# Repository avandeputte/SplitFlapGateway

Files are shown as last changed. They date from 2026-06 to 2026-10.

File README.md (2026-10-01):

# Split-Flap Gateway

> ### 🌐 [splitflap.iothing.net](https://splitflap.iothing.net) · 📖 [Documentation](https://splitflap.iothing.net/docs/)
> Quick start · choosing a configuration · provisioning & calibration · the SplitFlap,
> Matrix and LCD gateways · the companion and its apps · APIs and wire protocols — the
> whole ecosystem, documented in one place.

**Firmware version: 3.8.0**

> [!NOTE]
> **New to this project?** Read the [blog post](BLOG.md) for the full story — why it exists, how it works, and how it fits into the split-flap display ecosystem. Calibrating a module? See the **[Module Calibration Guide](CALIBRATION_GUIDE.md)**.

> [!TIP]
> **New in 3.8** (everything since 3.4 — see [RELEASE_NOTES.md](RELEASE_NOTES.md) for the full list)
> - **`GET /api/capabilities`** — one call that tells a client exactly what characters the wall
>   can show (`union`, the wall-wide `common` set, and each distinct reel with the module ids that
>   carry it). The Matrix Portal gateway answers the same URL identically, so a client never has
>   to know which kind of wall it is driving. See [New in 3.7](#new-in-37).
> - **`POST /api/display/cells`** — set a whole row in one call (`{ch|color|blank|skip}` per cell,
>   named colours, cascade pacing), the same contract the Matrix gateway answers, so the companion
>   drives both walls through one endpoint. See [New in 3.8](#new-in-38).
> - **Quiet Time now blanks the wall**, and **every gateway has its own MQTT identity** (two on one
>   broker used to knock each other offline).
> - **Safer web OTA and a security fix** — the watchdog no longer reboots the board mid-flash, and
>   a remotely-reachable buffer overflow in the by-serial flap-config command is closed.

> [!TIP]
> **New in 3.5**
> - **The dashboard speaks your language** — 13 languages plus English, chosen
>   automatically from your **browser** (the same way the light/dark theme is), with an
>   override in Settings and a `?lang=` URL parameter so the companion can request one.
>   All of them ship in the one firmware image. See [Language](#language).
> - **Re-skin fixes** — the Home Assistant theme left several controls behind, and in the
>   **light** theme some were *invisible*: every secondary button (Refresh, Identify All,
>   Home All, Re-read EEPROM) rendered white-on-near-white, and the destructive-action
>   buttons and bus-monitor text were unreadable. All fixed, and every element now clears
>   WCAG AA in both themes. **If you are on v3.4, this is the reason to update.**

> [!TIP]
> **New in 3.4**
> - **A new look** — the dashboard now wears the same **Home Assistant design
>   language** as the companion, so the two feel like one product. It follows your
>   browser/OS **light or dark** preference.
> - **Backup & restore moved into Settings** — the separate **Backup** tab is gone
>   (an old `#backup` link now lands on Settings). Nothing about the backup format
>   or the restore-by-serial behaviour changed.
> - **Tab advertisement** — the gateway and the companion now **tell each other
>   which tabs they have** (`tabs` / `gwTabs` on `POST /api/companion`), so neither
>   hard-codes a list of the other's. Old↔new pairings both still work.
> - **A steadier web server** — batch pacing no longer blocks the HTTP server (see
>   [Batch pacing](#batch-pacing-v34)), the module list streams in chunks (fixing a
>   watchdog reboot on large walls), and a changed MQTT broker now takes effect
>   without a reboot.

> [!TIP]
> **New in 3.2**
> - **Home All** — the Display and Calibration tabs each gained a **Home All**
>   button that homes every module at once (broadcasts `m*h`).

> [!TIP]
> **New in 3.1**
> - **Companion settings stored on the gateway** — the [Companion App](#companion-app)
>   can now park its settings, playlists and triggers in the gateway's flash
>   (`GET`/`PUT /api/companion/settings`), so a companion container becomes
>   stateless: spin one up on any host and it inherits its configuration from the
>   gateway. See [Companion Settings Storage](#companion-settings-storage).
> - **Firmware version in `/api/config`** — the config response now carries a
>   `"version"` field (e.g. `"3.1.0"`), which is how the companion detects a
>   gateway new enough to store its settings.

> [!TIP]
> **New in 3.0**
> - **Batch RS-485 send** — `POST /api/rs485/batch` sends many frames in one
>   request (with optional device-side pacing), so a host can draw a whole
>   animated page in a single HTTP call instead of one request per module.
> - **Quiet-Time schedule** — Quiet Time can now turn on/off automatically on a
>   daily schedule (Settings → *Quiet Time Schedule*: a start/end time and the
>   days it applies). Evaluated once a second against the RTC.
> - **Companion app** — the companion that adds apps, playlists and triggers is
>   **released**: [SplitFlapGatewayCompanion](https://github.com/avandeputte/SplitFlapGatewayCompanion).

---

> [!IMPORTANT]
> **This project is designed to work with the Split-Flap display from [Adam G Makes](https://www.youtube.com/@AdamGMakes).**
> See [this video](https://youtu.be/-C8_AtxEEQc?si=Gym5wikeFH2vUNRm) for additional information.
>
> - **Basic functionality** (sending characters and text to the display) works with Adam's original firmware using hardcoded module IDs — no provisioning required.
> - **Full functionality** (module discovery, dynamic ID assignment, and provisioning) requires the universal firmware: [avandeputte/SplitFlapUniversalFirmware](https://github.com/avandeputte/SplitFlapUniversalFirmware).

---

## New in 3.7

- **`GET /api/capabilities`** — one call that answers *what characters can this wall show?* The
  Matrix Portal gateway answers the same URL with the same shape, so a client never has to know
  which kind of wall it is talking to.

  On a real wall the answer is not one set. Every module owns its reel, and since module firmware
  v31 each can be told a *different* one (`N`), so the response reports both:

  | field | question it answers |
  |---|---|
  | `union` | can this wall show a `Z` **anywhere**? |
  | `common` | can I lay this text across **arbitrary** cells? |

  These genuinely differ. If module 1 carries `A-Z` and module 2 carries `0-9`, the union is
  `A-Z0-9` but the common set is *empty* — the wall cannot show `HI42` wherever it likes, and
  only `common` says so. `sets` then lists each **distinct** reel once with the ids that carry it
  (`"0-44,50"`), so a uniform wall is a few hundred bytes however large it is.

  Two translations are applied, matching exactly what the gateway does when it resolves a frame:
  the seven colour flaps `r o y g b p w` are reported by name under `colors` and kept *out* of the
  character sets, and `q` — which the classic reel borrows for the double-quote flap — is reported
  as `"`. A client that read those as letters would believe a classic reel can show a lowercase
  `w`.

- **The registry now remembers each module's flap set**, read from the v31+ tail of an `A` reply
  and **persisted**. That is not an optimisation: an `A` reply is ~200 bytes, so asking a
  45-module wall costs about **ninety seconds of bus time** at 9600 baud. Paying that on every
  reboot — or flooding the bus with a wall-wide `m*A` at boot — would be absurd. Unknown sets are
  filled by a slow background trickle (one module every 2 s), a set is re-read only when an `N`
  deliberately changes it, and the file magic is bumped to `SFG3`.

  Modules older than v31 cannot report a set. Their reel is *assumed* to be the firmware's
  built-in default and their ids are listed under `charset.assumed`, so the guess is visible
  rather than folded in silently — a gateway that hid it would be lying at exactly the moment
  someone had reflashed a module with a custom reel. Modules whose set is genuinely not known yet
  are listed under `unknown` and excluded from both character sets.

- **`tools/capset_test.cpp`** — the set arithmetic (union, intersection, range compression, the
  `q` and colour translations) compiles the firmware's own `src/capset.h`, so the test exercises
  the shipped code rather than a copy of it. It covers the case that cannot be reproduced without
  physically rebuilding the wall: modules with different reels.

## New in 3.8

- **`POST /api/display/cells`** — set a run of modules in one call, the **same JSON contract the
  Matrix Portal gateway answers**, so a client (the companion) can drive both walls through one
  display endpoint instead of this wall's batch/char path and the Matrix's cells path. It is the
  "show this" companion to `GET /api/capabilities` ("what can you show").

  ```json
  { "start": 0, "step_ms": 15,
    "cells": [ {"ch":"H"}, {"ch":"I"}, {"color":"red"}, {"blank":true}, {"skip":true} ] }
  ```

  Each cell is exactly one of `ch` (a character), `color` (a named flag: red orange yellow green
  blue purple white), `blank` (home the module), or `skip` (leave it alone). `step_ms` (0–100)
  paces the cascade, scheduled on the RS-485 task rather than blocking the web server.

  It is **lenient**, and that is the one real difference from the Matrix's strict form: this wall's
  modules each carry their own reel and can differ, so a cell that cannot be shown (a glyph absent
  from the reel, an unknown colour name) is **skipped** rather than failing the whole row — the
  response reports `sent` vs `skipped`. Only structural errors (bad JSON, missing `cells`) return
  400. A client that needs certainty consults `/api/capabilities` first.

  Sent **by character** (`m<id>-<char>`), not by index like the Matrix: index *N* names a different
  glyph on a module with a different reel, whereas the byte lets each module map it against its own.

## New in 3.12

- **Restore on boot** — upload a calibration backup to the gateway and have it **replayed to
  every module on every boot**. Each module's calibration (home offset, steps per revolution,
  flap map, and a v31+ flap set) and its **ID** are written by serial number, read back and
  verified, and the whole wall is homed at the end. While it runs the gateway **refuses every
  other module command** — REST answers `503 {"error":"restore in progress"}`, MQTT commands
  are dropped — and the dashboard shows a red border and banner with the progress. It always
  finishes on its own (a module that never answers is counted, not waited for), and it can be
  started or cancelled by hand. Settings tab → **Restore on Boot**; see
  [Restore on Boot](#restore-on-boot).

## Table of Contents

- [Hardware](#hardware)
- [Features](#features)
- [Installation](#installation)
- [Serial Debug Output](#serial-debug-output)
- [First Boot](#first-boot)
- [Web UI](#web-ui)
  - [Language](#language)
- [Companion App](#companion-app)
  - [Companion Settings Storage](#companion-settings-storage)
- [Module List Persistence](#module-list-persistence)
- [Restore on Boot](#restore-on-boot)
- [Split-Flap Protocol](#split-flap-protocol)
- [REST API](#rest-api)
  - [RS-485 Bus](#rs-485-bus)
  - [Module Control](#module-control)
  - [Advanced Module Commands](#advanced-module-commands)
  - [Provisioning](#provisioning)
  - [Status and Configuration](#status-and-configuration)
  - [OTA Firmware Update](#ota-firmware-update)
- [OpenAPI Specification](#openapi-specification)
- [MQTT](#mqtt)
- [Time Configuration](#time-configuration)
- [OTA Firmware Updates](#ota-firmware-updates)
- [Default Settings](#default-settings)
- [License](#license)

---

## Hardware

**Target board:** [Waveshare ESP32-S3-RS485-CAN](https://www.waveshare.com/wiki/ESP32-S3-RS485-CAN) — [Buy on Amazon](https://www.amazon.com/dp/B0FNCWZ3D1?ref=ppx_yo2ov_dt_b_fed_asin_title)

| Function | Pin |
|---|---|
| RS-485 TX | GPIO 17 |
| RS-485 RX | GPIO 18 |
| RS-485 DE/RE | GPIO 21 |
| I²C SDA (RTC) | GPIO 39 |
| I²C SCL (RTC) | GPIO 38 |
| RTC chip | PCF85063 @ 0x51 |
| Debug serial | Native USB CDC (`/dev/cu.usbmodem*` on macOS, `COMx` on Windows, `/dev/ttyACM0` on Linux) |

The RS-485 bus runs at **9600 baud, 8N1**.

> **Mount it on the rail.** [`SplitFlapGatewayCase.3mf`](SplitFlapGatewayCase.3mf) is a printed
> case that replaces the Waveshare enclosure, clips the gateway onto the modules' DIN rail, and
> takes 12 V and the RS-485 bus from the conductor rail through four pogo pins — no wiring to
> the wall at all. The build, and the soldering it needs, is on the wiki:
> **[Gateway Case](https://splitflap.iothing.net/docs/Gateway-Case/)**.

---

## Features

- **Web UI** — single-page dashboard accessible from any browser, in the same **Home Assistant design language** as the companion (light or dark, following your browser/OS)
- **[Companion app](#companion-app)** — an optional content engine (apps, playlists, schedules, triggers) that runs on a Raspberry Pi or any Linux box and drives the display over REST. It registers itself with the gateway, which then shows a **Companion** tab, and it can keep its own settings in the gateway's flash so its container stays stateless
- **Module management** — discover, provision, home, calibrate, and deprovision split-flap modules (up to 255: IDs 0-254)
- **Permanent module list** — the known-module registry persists across reboots in flash and **(v3.12)** is never pruned: a module not heard from in a day is re-queried so its record stays current, but only Identify All or De-provision removes one. A gateway that boots with an empty list broadcasts `m*v` to rediscover modules automatically
- **Per-module actions** — each module card has Home, Info, and destructive-action icons. The Info dialog shows all known module data plus a parsed view of its EEPROM (home offset, steps/rev, and the calibrated flap map). The destructive-actions dialog (red trash icon) offers Erase EEPROM, Factory Reset, and De-provision, each with a confirmation prompt
- **Backup & restore** — on the Settings tab: download all module calibration to a JSON file and restore it later by serial number, with an option to also reassign module IDs (a v31+ module's configurable flap set is captured and restored too)
- **Restore on boot** — **(v3.12)** keep a backup file on the gateway and replay it to every module on **every boot**: calibration and IDs are written by serial number, read back and verified, then the wall is homed. While it runs the gateway refuses every other module command (REST answers 503, MQTT commands are dropped) and the dashboard shows a red border and banner; it always finishes on its own, and can be run or cancelled by hand. See [Restore on Boot](#restore-on-boot)
- **Configurable flap set** — modules on firmware v31+ let you set the active flap count (1–64) and the ordered character set per module from the Info dialog, or push one set to a whole panel with a broadcast; the live values are read back from the `A` dump and persist in module EEPROM. Characters aren't limited to ASCII: the **euro sign `€` and accented letters** (Windows-1252) are supported — type them as UTF-8 and the gateway transcodes to the single byte the bus uses
- **Module self-diagnostics** — modules on firmware v26+ gain a 🩺 icon that runs three built-in tests and interprets the results: an instant **stats snapshot** (reset cause, boot count, supply voltage, EEPROM verify, current flap index), a **Hall sensor self-test** (home-sensor health), and a motor-driven **mechanical self-test** that detects intermittent missed steps (drag / weak supply / failing driver) or a stalled reel — with a selectable rotation count (5–20, firmware v29+) for deeper runs
- **Connection test** — a "Test Connection" button on the Settings tab verifies MQTT broker reachability and credentials before saving
- **Health metrics** — the Status tab shows minimum-ever free heap and per-task stack high-water marks, surfacing memory pressure before it causes a crash
- **Diagnostic boot/telemetry log** — on boot the gateway prints its reset reason (POWERON / PANIC / TASK_WDT / BROWNOUT, etc.), a chip/heap snapshot, and where its large buffers were allocated (`[MEM] … in PSRAM`); the periodic `[WDG]` line reports heap, min-ever heap, largest free block, heap-fragmentation %, per-task stack watermarks, RX/TX/parse-reject counters, WiFi station and fallback-AP state, WiFi RSSI, and MQTT state
- **PSRAM-backed buffers** — the bus-monitor ring, MQTT publish queue, and module registry (~60 KB combined) live in the board's PSRAM, keeping internal RAM free for the WiFi/TCP stack (which makes large over-the-air updates reliable); falls back to internal RAM if PSRAM is unavailable
- **mDNS** — the web UI is reachable at `http://splitflap-gw.local` (no IP lookup needed)
- **Maintenance mode** — makes the gateway ignore all externally-originated MQTT commands (the web UI keeps working), so calibration and backup work isn't disturbed by home-automation traffic. Enable it from the Calibration tab or via REST/MQTT/Home Assistant; while it's on, the dashboard shows a yellow border and a banner with a one-click **Turn Off**. Always resets to off on reboot
- **Quiet time** — controllable via REST/MQTT/Home Assistant or a daily schedule (Settings → *Quiet Time Schedule*). **Turning it on blanks the wall**: every reel is homed to its blank flap, so the display goes empty for the night. The gateway stays responsive to commands, but stops moving any flaps for normal display updates; deliberate calibration moves still work. A teal border and banner mark the dashboard while it's active. **Turning it off restores the wall** — the reels resync to whatever was last requested while quiet, or to what they were showing when quiet began. Always resets to off on reboot
- **Home Assistant integration** — optional MQTT auto-discovery (opt-in on the Settings tab) that exposes the gateway as a Home Assistant device: a display text control, Maintenance and Quiet Time switches, an availability sensor (via MQTT LWT), and the full `[WDG]` diagnostic set as sensors, plus a clickable Gateway URL
- **Real-time bus monitor** — live RS-485 traffic with protocol decoding and local timestamps
- **NTP time sync** — RTC backed by PCF85063; syncs on WiFi connect and persists through power loss. The NTP server is configurable in Settings (default `pool.ntp.org`)
- **DST-aware timezone** — POSIX TZ string support covering 20 regions, takes effect immediately
- **MQTT integration** — publishes bus frames and module events; subscribes to control topics
- **REST API** — full JSON API for programmatic control (OpenAPI spec included)
- **OTA updates** — flash new firmware over WiFi from a browser (or `espota`); no USB cable required after first flash
- **Fallback AP** — when no network is configured (or the WiFi connection is lost for ~20 s), the gateway brings up its own access point for setup; once connected to your WiFi it runs station-only and shuts the AP down automatically
- **Configurable serial debug** — verbose logging toggled from the web UI Settings tab
- **Watchdog** — detects stalled FreeRTOS tasks and auto-reboots; emergency reboot on low heap

---

## Installation

This repo is a **[PlatformIO](https://platformio.org/) project** (`platformio.ini`).
Building from the **Arduino IDE is no longer supported** (there is no `.ino` sketch).
There are two ways to get the firmware onto a board:

- **Flash a prebuilt binary — no build environment needed.** A precompiled image is
  published on the [Releases](https://github.com/avandeputte/SplitFlapGateway/releases)
  page and can be flashed directly. See
  [SETUP.md ▸ Flash a prebuilt binary](SETUP.md#flash-a-prebuilt-binary-no-build-environment-needed).

- **Build from source with VS Code + PlatformIO.** The complete step-by-step guide —
  installing VS Code, building, flashing over USB, and OTA updates — is in
  **[SETUP.md](SETUP.md)**. PlatformIO downloads the ESP32 toolchain and the required
  libraries (`PubSubClient`, `ArduinoJson`) **automatically** on the first build, and
  every board setting (PSRAM, 16 MB flash, the 3 MB-app / 9.9 MB-FATFS partition
  scheme, USB mode, CPU speed, etc.) is already encoded in `platformio.ini` — there is
  nothing to install or configure by hand.

  ```bash
  # quickest path once VS Code + PlatformIO are installed (see SETUP.md):
  pio run -t upload      # build + flash over USB
  pio device monitor     # view serial output (115200 baud)
  ```

After the first USB flash, all subsequent firmware updates can be done
[over WiFi](#ota-firmware-updates).

---

## Serial Debug Output

The firmware outputs diagnostic messages at **115200 baud** over the board's native
USB CDC port (the serial monitor baud is preset in `platformio.ini`; open it with the
PlatformIO **Monitor** / `pio device monitor`, or any serial terminal).

| OS | Port |
|---|---|
| macOS | `/dev/cu.usbmodem*` (e.g. `/dev/cu.usbmodem114101`) |
| Windows | `COMx` — listed as "USB Serial Device" in Device Manager |
| Linux | `/dev/ttyACM0` |

**Always-on messages:**
```
[Boot] Split-Flap Gateway v3.5.0
[Boot] reset=PANIC heap=261540 psram=8388608 flash=16384KB sdk=v5.1.4
[MOD] Loaded 11 modules from FATFS (0 pruned as stale)
[WiFi] Connected IP=192.168.1.105
[MEM] monitor ring in PSRAM (18944 bytes)
[MEM] MQTT queue in PSRAM (26240 bytes)
[MEM] module registry in PSRAM (15300 bytes)
[MQTT] Connecting to broker:1883...
[WDG] up=30s heap=164484 min=84632 maxblk=118772 frag=28% stk(485/web/net/ota/rtc)=4724/4756/2684/2812/748 rx=12 tx=9 rej=0 wifi=1 ap=0 rssi=-58 mqtt=1 mods=11
```

The boot line's `reset=` field is the first thing to check after an unexpected reboot:

| reset reason | meaning |
|---|---|
| `POWERON` | normal power-up |
| `SW` | software reset (e.g. after an OTA flash or config change) |
| `PANIC` | firmware crash (stack overflow, null deref, assert) — check the backtrace above it |
| `TASK_WDT` / `INT_WDT` | a task or interrupt blocked too long |
| `BROWNOUT` | supply voltage dipped — a power problem, not firmware |

The `[MEM]` lines report where the three large runtime buffers landed — PSRAM when available (preferred, to keep internal RAM free for the WiFi/TCP stack during OTA), or internal RAM as a fallback.

The periodic `[WDG]` fields: `heap` (free now), `min` (lowest free heap ever — catches transient dips), `maxblk` (largest allocatable block), `frag` (heap fragmentation %; a high value with adequate `heap` warns of fragmentation before an allocation fails), `stk(...)` (per-task minimum-ever free stack in bytes — a value trending toward 0 predicts a stack-overflow crash), `rx`/`tx` (bus frame counters), `rej` (corrupt/garbled frames rejected at parse — a rising count signals bus collisions or wiring noise), `wifi` (station connected to your network), `ap` (fallback access point currently up — should be `0` whenever `wifi=1`), `rssi` (WiFi signal), and `mqtt` (broker connected). A stall reboot logs which task stalled and its age; a low-heap reboot logs the heap value.

**Debug messages** (enable in Settings → Serial Debug):
```
[RX] m5v:12:5:AABBCCDD  (2026-06-10 14:32:01)
[TX] m5-A
[MQTT->BUS] m9h
[NTP] Syncing (UTC) via pool.ntp.org...
[SF] rejecting corrupt version response for module 5 (sn:...)
[API] home module 9
[API] provision SN AABBCCDD -> ID 5
[CFG] MQTT broker set to 192.168.1.50:1883  prefix=splitflap
[CFG] NTP server set to time.google.com
[CFG] Timezone set to EST5EDT,M3.2.0,M11.1.0
```

---

## First Boot

With no WiFi configured, the gateway brings up a fallback Access Point so you can reach the setup page:

| Setting | Value |
|---|---|
| SSID | `Split-Flap-GW` |
| Password | `12345678` |
| Web UI | http://192.168.4.1 |

Connect to the AP, open the web UI, go to **Settings → WiFi**, enter your network credentials, and click **Save WiFi**. The gateway connects to your network; its IP appears on the **Status** page (and in the serial log). NTP syncs automatically on first WiFi connection.

The Access Point is **fallback-only**: once the gateway is connected to your WiFi it runs station-only and the AP is shut down (so it can't be joined by mistake, and its resources stay free). The AP only comes back if the station connection is lost for more than ~20 seconds, and it drops again automatically when the connection returns. You can confirm the AP is off in the `[WDG]` serial log — `ap=0` whenever `wifi=1`.

---

## Web UI

Navigate to the gateway's IP address in any browser.

Since **v3.4** the dashboard wears the **Home Assistant design language** — the same
look the [companion](#companion-app) ships, so the two halves feel like one product
rather than two tools bolted together. It follows your browser/OS **light or dark**
preference automatically; there is no theme setting to configure.

<p align="center">
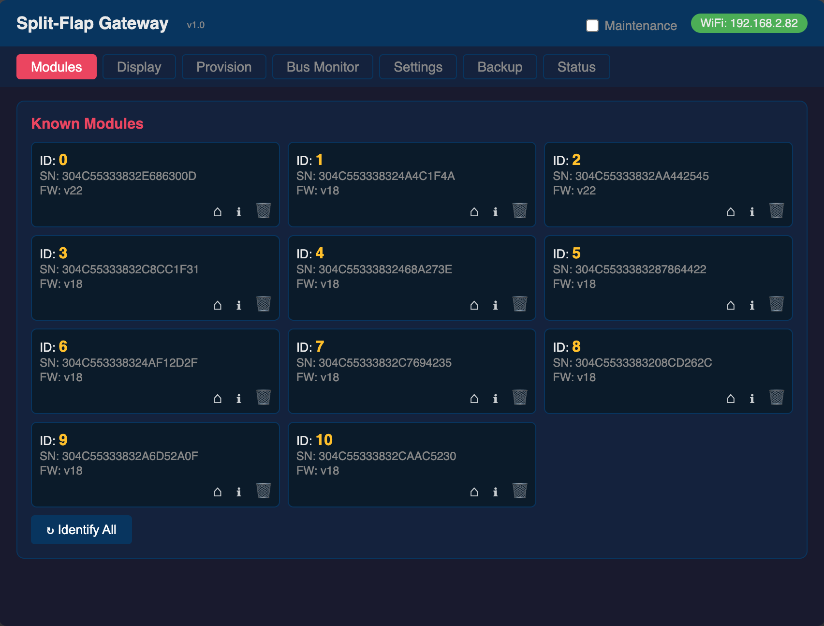
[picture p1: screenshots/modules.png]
Modules tab

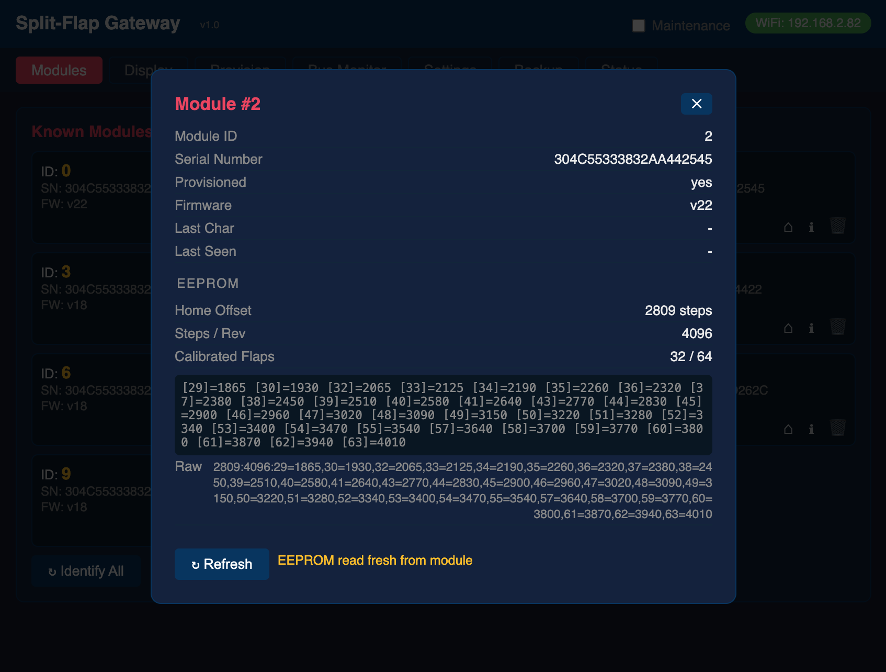
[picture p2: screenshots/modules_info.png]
Module info dialog with parsed EEPROM

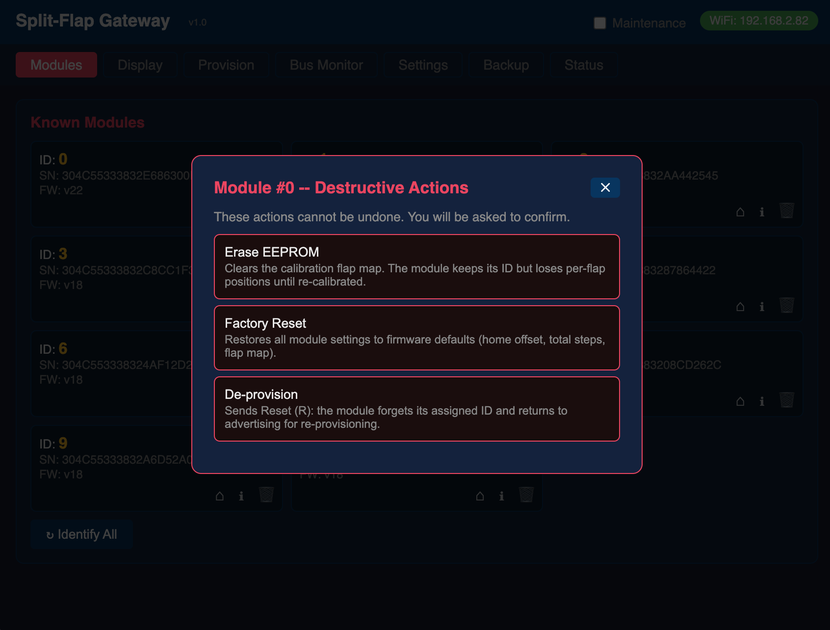
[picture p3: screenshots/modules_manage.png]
Module destructive-actions dialog

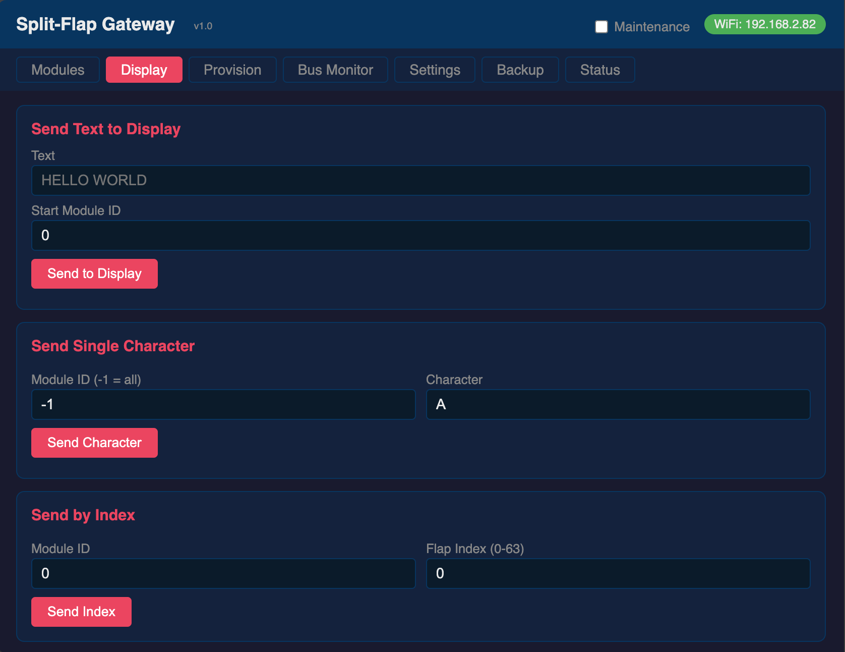
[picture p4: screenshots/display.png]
Display tab

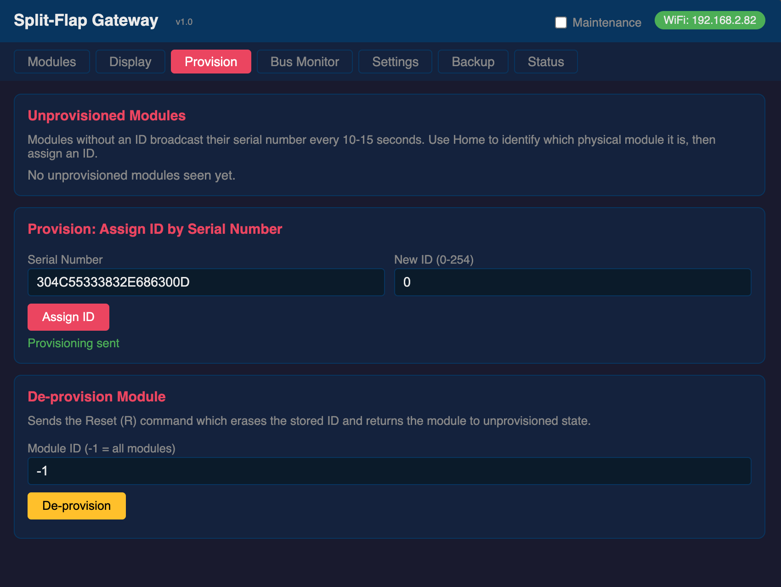
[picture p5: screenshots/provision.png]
Provision tab

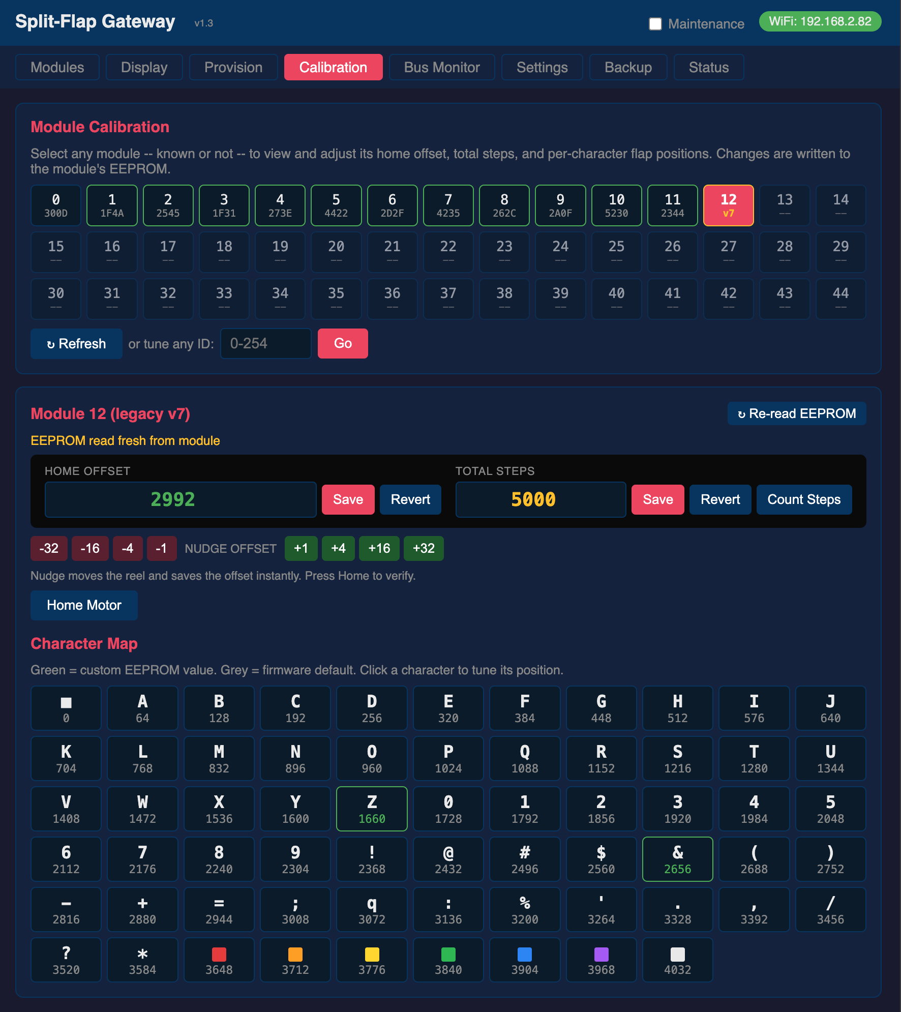
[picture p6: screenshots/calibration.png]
Calibration tab — module grid, in-place home offset and total steps with Count Steps, and the per-character map

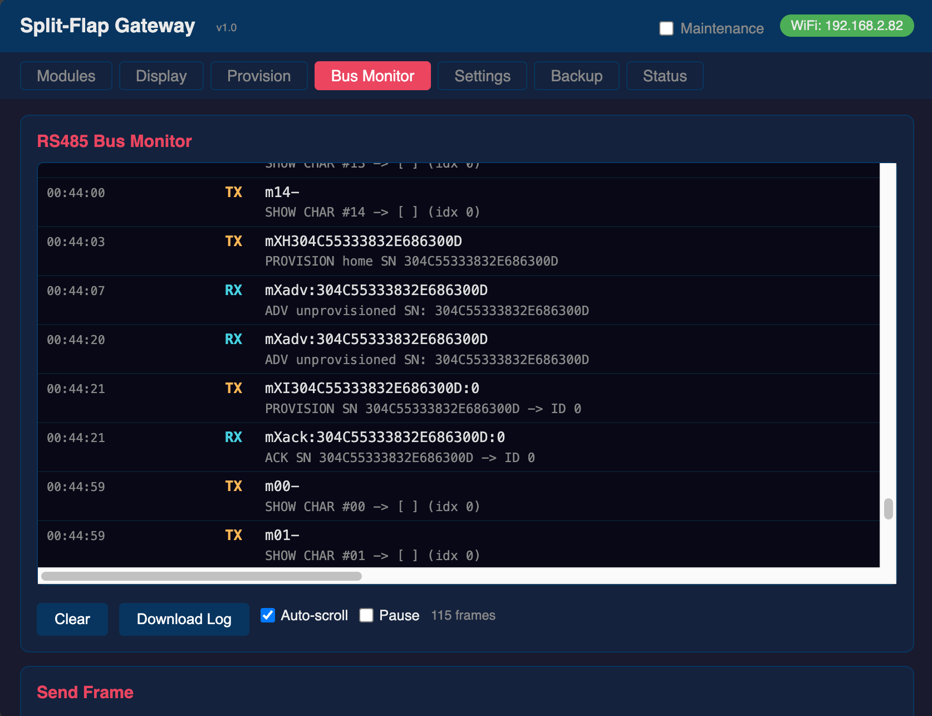
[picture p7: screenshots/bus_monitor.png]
Bus Monitor tab

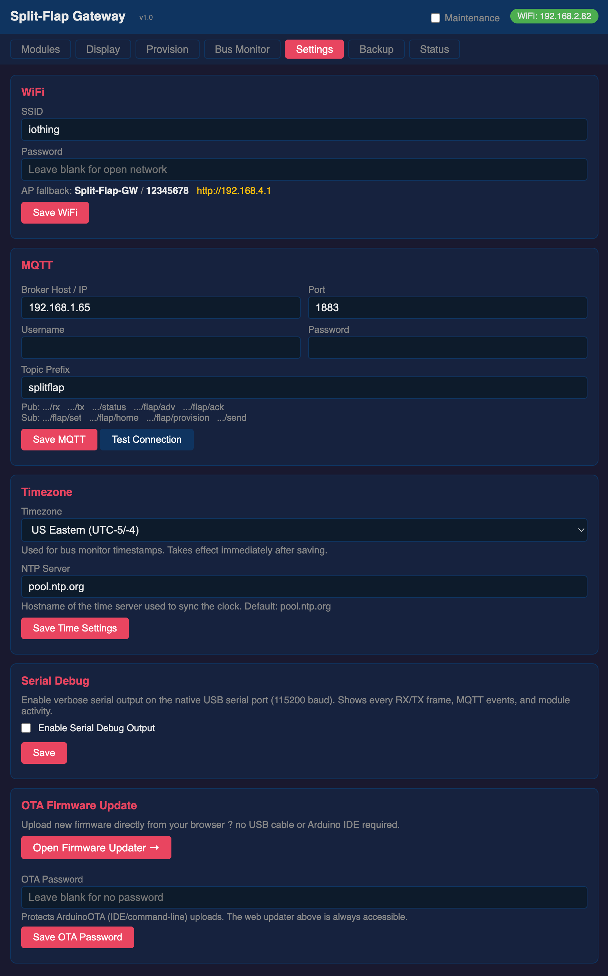
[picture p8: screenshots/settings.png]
Settings tab

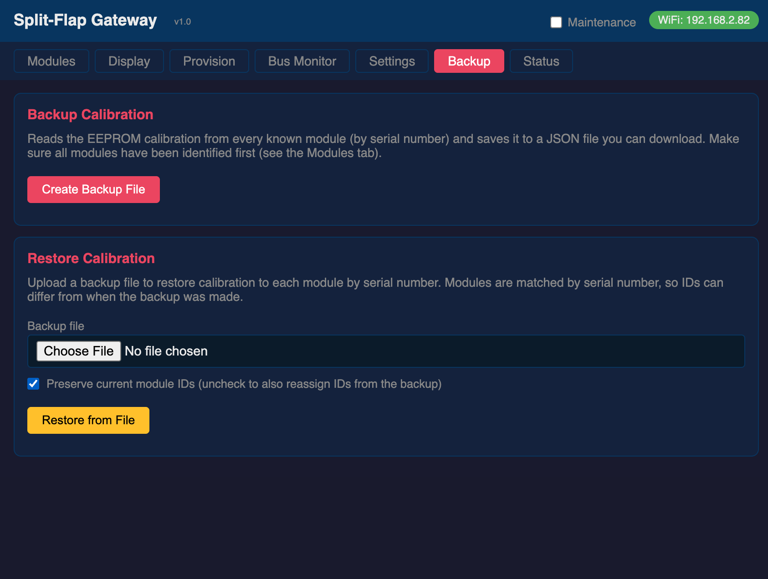
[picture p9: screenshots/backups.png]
Backup & restore, on the Settings tab

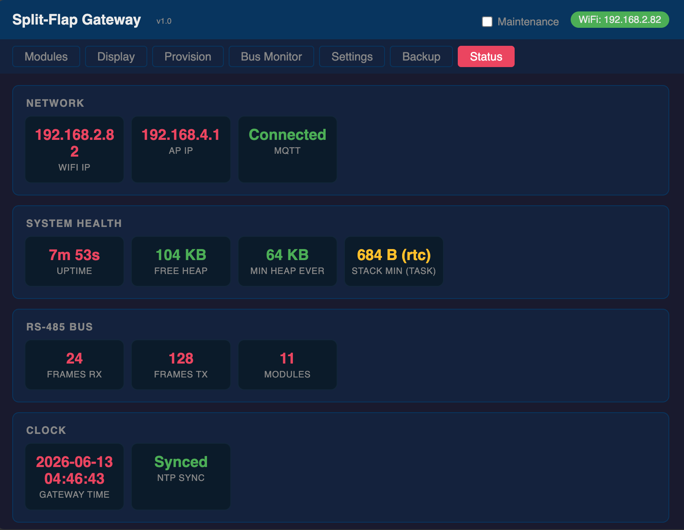
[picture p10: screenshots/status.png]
Status tab

</p>

| Tab | Description |
|---|---|
| **Modules** | Grid of all known modules — ID, serial number, current character, firmware version, sorted by ID (unprovisioned modules last). The list is sticky: it persists across reboots and only drops modules not seen for 6 hours. Each provisioned module card carries three action icons: **⌂ Home** (homes the module), **ℹ Info** (opens a dialog that queries the module live — refreshing its firmware version and reading its EEPROM — and shows all known module data plus a parsed view of the EEPROM: home offset, steps/rev, and the calibrated flap map — and, for a module on firmware v31+, an editable **Flap Set** section for the active flap count and character set), and a red **🗑 trash** icon that opens a destructive-actions dialog offering Erase EEPROM, Factory Reset, or De-provision, each behind a confirmation prompt. Modules running firmware v7 or earlier are flagged **LEGACY** (they have no serial number, no provisioning, and no factory reset, but full homing and calibration support); their unsupported destructive actions are greyed out. **↻ Identify All** clears the list (memory and saved file) and broadcasts `m*v` so every module re-announces itself. |
| **Display** | A **Live Display** at the top renders what the wall is currently showing as a grid of split-flap cells, updating as characters change, with a **Home All** button beneath it that homes every module at once (broadcasts `m*h`). Below it: send a text string across sequential modules by start ID, send a single character to one module (or broadcast to all), or send a specific flap index to a module |
| **Provision** | Discover unprovisioned modules, home by serial number to identify them physically, assign IDs, de-provision individually or all at once |
| **Calibration** | Fine-tune any module on the bus — known or not. The module picker is a grid matching your display layout (every position, IDs 0 to rows×cols−1), color-coded green (known), yellow (legacy v7), or dim (not yet seen); you can also type any ID directly, or **Home All** to home every module at once (broadcasts `m*h`). For the selected module you can edit and save **Home Offset** and **Total Steps** in place (each with Save and Revert-to-default), nudge the home offset live, and **Count Steps** (runs the calibrate command — the reel spins one revolution to measure steps/rev, then the measured value is written back). The character map shows every flap (in the module's own character order, with colour flaps as swatches) and its current step position (custom EEPROM values in green, firmware defaults in grey); clicking one opens a tune dialog to GOTO-test a target step, fine-adjust it with nudge buttons, then Lock to EEPROM or Revert (which unsets the entry so the flap uses its default again). A guided **Calibration Wizard** steps through every flap one at a time. The map, the Wizard, and the whole-board walk all honour a module's **custom flap set** (character order and flap count) on firmware v31+, falling back to the default 64-flap reel on older modules. See the **[Module Calibration Guide](CALIBRATION_GUIDE.md)** for a full walkthrough. |
| **Bus Monitor** | Live decoded RS-485 traffic with timestamps shown in your browser's local timezone. Pause and auto-scroll preferences persist across visits, and **Download Log** saves the captured frames (up to 5000 lines) as a text file. A **Send Frame** box transmits an arbitrary frame; the gateway normalizes framing and trims trailing junk by default, with a **Raw** checkbox to send bytes verbatim for debugging. |
| **Settings** | **Language** (defaults to *Auto*, which follows your browser — see [Language](#language)), WiFi credentials, MQTT broker, timezone, NTP server, display layout (rows x columns for the Live Display), serial debug toggle, OTA firmware update, and **backup & restore** — download a JSON backup of every module's EEPROM calibration (keyed by serial number), and restore calibration from a backup file. Restore matches modules by serial number; an option lets you also reassign module IDs from the backup. **(v3.12)** **Restore on Boot** — store a backup on the gateway, and have it replayed on every boot (see [Restore on Boot](#restore-on-boot)). |
| **Status** | Grouped into Network, System Health, RS-485 Bus, and Clock sections. Shows uptime, frame counters, IP addresses, free heap, minimum-ever heap, lowest per-task stack headroom, MQTT state, RTC time, and NTP sync — with color-coded health indicators |

### Language

The dashboard is available in **English plus 13 other languages**, and picks one the same
way it already picks light or dark: **it follows your browser**. There is nothing to
configure.

The choice is made in this order, first match wins:

1. **`?lang=<code>` in the URL** — `http://splitflap-gw.local/?lang=fr`. This wins over
   everything and is deliberately **not saved**, so the [companion](#companion-app) can
   request a language for an embedded view without changing what *you* see.
2. **Settings ▸ Language** — an explicit override. Stored in your browser, so it is
   per-device; the gateway keeps no language state at all.
3. **Your browser** (`Auto`, the default). `en-GB` and `en-AU` browsers get British and
   Australian spelling automatically.
4. **English**, if none of the above match.

**The languages** are the ones whose text the split-flap modules could actually display —
the Windows-1252 (Western European) repertoire — so the dashboard and the wall speak the
same set:

| | |
|---|---|
| English | US *(built in)*, UK, Australia |
| Romance | French, Spanish, Italian, Portuguese (Portugal), Portuguese (Brazil) |
| Germanic | German, Dutch |
| Nordic | Danish, Swedish, Norwegian, Finnish |

**All of them ship in the one firmware image** — there is no per-language build, and
switching language never means reflashing. That is affordable because only the *words* are
duplicated, not the page: the dashboard is 109 KB of HTML/CSS/JS but only ~11 KB of it is
English *text*, and a dictionary (which carries the English key alongside each translation)
compresses to about **9 KB** — so all 13 languages together cost roughly **115 KB of flash**,
under 7% of the free space. The browser downloads only the one dictionary it needs
(`GET /lang/<code>`, gzipped), and English downloads nothing at all — it is the text already
in the page.

That also makes translations **safely partial**: any string a translator left alone falls
back to English on its own, so a missing word never breaks a screen. (It is why the British
dictionary is 7 entries — only 7 strings actually differ.)

The **bus monitor is deliberately never translated**: it shows RS-485 frames and their
decode, which is protocol, not prose.

> **Adding or fixing a language.** Edit `ui/strings/<code>.json` — the keys are the English
> strings themselves. Then `python3 tools/build_ui.py` regenerates `src/web_ui.h`.
> `tools/i18n_check.py` validates every dictionary (unknown keys, dropped product name,
> non-Windows-1252 characters) and `node tools/i18n_test.js` covers the language-matching
> rules.

---

## Companion App

The gateway owns the **hardware**: the RS-485 bus, module discovery, provisioning,
calibration and diagnostics. It has no concept of a "weather app" or a playlist.
That's the job of the **companion** — an optional web app that owns the
**content** and drives this gateway over REST.

> **Get it:** **[avandeputte/SplitFlapGatewayCompanion](https://github.com/avandeputte/SplitFlapGatewayCompanion)**

The two run on separate machines (the companion wants a Raspberry Pi, a NAS, or any
x86-64 Linux box — anything that can run Docker) but are meant to feel like **one
integrated product**: they share the same look, and a unified tab bar cross-links
between them. The companion registers itself with the gateway, which then grows a
**Companion** tab pointing back at it, and reports the companion's running status on
the **Status** page.

**What it does:**

| | |
|---|---|
| **Apps** | 45 ready-made apps — clocks, weather, stocks, crypto, sports scores, transit times, countdowns, quotes, animations. Tile grid, one-tap run |
| **Compose** | A click-to-type grid with colour tiles and every transition style (`ltr`, `rtl`, `spiral`, `slot`, …) |
| **Playlists** | Sequence apps and messages with per-entry durations and per-entry settings, then save, run and loop them |
| **Schedules** | Time-of-day windows, per weekday, that run an app or playlist — or turn the display off |
| **Triggers** | Apps that watch for an event (the ISS overhead, a goal, a storm) and briefly interrupt whatever is showing |
| **Localization** | A global language (US/UK/Australian English plus the Western-European languages that fit the modules' Windows-1252 flaps), with currency and public holidays following your location. Both overridable per app |
| **App Library** | Add, remove, or **upload your own** apps as a `.zip` — the app format is [csader/splitflap-os](https://github.com/csader/splitflap-os)'s plugin library, reused through a behavior-identical runtime, so any splitflap-os app drops in unchanged |
| **Display tab** | This gateway's own calibration/modules/diagnostics UI, reverse-proxied under the companion's origin so the whole thing is one app |
| **Home Assistant** | Adds **App** and **Playlist** selects and a **Stop** button — the companion-unique controls the gateway's own HA device doesn't cover |

**How it talks to this gateway:**

- **Always REST.** A whole page is drawn in one `POST /api/rs485/batch` request — the
  v3.0 endpoint exists precisely for this. No broker sits in the display path, so
  animations stay smooth. Each batch shows as a single **REST** row in the Bus Monitor.
- **MQTT only for Home Assistant.** It never carries display frames.
- **This gateway is the source of truth.** The companion reads its grid size and MQTT
  broker from `GET /api/config` on startup and on demand, rather than keeping its own copy.
- **It registers itself** with `POST /api/companion` (its URL, plus a status heartbeat).
- **Each side advertises its own tabs** in that same exchange (v3.4). The companion sends
  the deep links its UI has (`tabs`), the gateway answers with its own (`gwTabs`), and each
  nav links exactly what the other really has — so a tab added or removed on one side shows
  up on the other without a matching release. Both halves are optional: an older peer that
  says nothing simply gets the built-in list, which is why any old/new pairing still works.

Install is a single command on a Pi or any Linux box — it installs Docker if needed,
asks for this gateway's URL, and starts the container:

```bash
curl -fsSL https://raw.githubusercontent.com/avandeputte/SplitFlapGatewayCompanion/main/install.sh | bash
```

> The companion **requires Gateway 3.0 or newer** (it depends on batch send and
> `/api/companion` registration), and it is licensed CC BY-NC-SA 4.0 as a derivative
> of splitflap-os. This gateway's own firmware is unaffected — the companion is
> entirely optional, and the gateway works standalone without it.

### Companion Settings Storage

**New in firmware 3.1.** The companion can store its settings, playlists and triggers
**in this gateway's flash** instead of on its own disk. A companion container then
becomes effectively **stateless**: destroy it, start another on a different host, and
it restores its configuration from the gateway on boot.

The gateway is deliberately a **dumb blob store**. The payload is
`gzip(minified JSON)` whose schema belongs entirely to the companion; the firmware
stores the bytes **verbatim**, hands them back byte-for-byte, and never parses them.

| Endpoint | Behavior |
|---|---|
| `GET /api/companion/settings` | Returns the stored gzipped body as `application/gzip`, or **404** when nothing is stored yet |
| `PUT /api/companion/settings` | Stores the gzipped request body, atomically. Replies `200 {"ok":true,"bytes":N}` |

Details worth knowing:

- **Atomic writes.** The body streams to a temp file which is renamed over the live
  one only once the last byte has landed, so a crash or a dropped connection
  mid-upload can never corrupt settings that were already good.
- **No `Content-Encoding: gzip`.** The gzip bytes *are* the payload, not a transfer
  encoding of it — declaring the encoding would make HTTP clients silently
  decompress the body, and the companion decompresses it itself.
- **It survives OTA updates.** The blob lives on the FATFS partition
  (`/compset.gz`), which a firmware update doesn't touch.
- **Bounded.** A blob larger than 64 KB is rejected with `413`. Real ones are 1–2 KB,
  so this costs the gateway negligible flash; the companion also debounces its writes
  so a burst of edits becomes one write.
- **Errors:** `400` empty or truncated body, `413` too large, `503` filesystem not
  mounted, `507` write failed.

On the companion side this is the `COMPANION_SETTINGS_STORE` setting — `mirror`
(default: local file primary, mirrored here), `local` (never touch the gateway), or
`gateway` (diskless, stored only here). It's backward compatible: against a **3.0**
gateway the companion sees no `"version"` field new enough in `/api/config` and
quietly falls back to local storage.

---

## Module List Persistence

The known-module list is **sticky**: it survives reboots and power cycles so the
dashboard isn't empty after a restart.

- Stored as a small file (`/modules.dat`) in the FATFS partition that already
  exists in the default partition scheme — no custom partition table or special
  configuration is needed.
- Only durable fields are saved (ID, serial number, provisioned flag, firmware
  version, and a last-seen wall-clock timestamp). Transient display state and
  EEPROM dumps are not persisted.
- **(v3.12)** The list is **permanent**. A module is never removed for being quiet:
  modules only speak when addressed, so "not seen" just means "nothing talked to
  it", and a wall that has been showing a static message for a week is still a
  wall. Instead, a module not heard from in **24 hours** is re-queried once a
  minute with a version query (`m<id>v`), a few at a time, so its firmware,
  serial and last-seen stay current and a swapped or re-flashed module is
  noticed; after four unanswered queries it is left alone for an hour and then
  asked again. Only **Identify All**, **De-provision**, or a corrupt record
  removes an entry. Because nothing has to be re-discovered, the module list and
  `GET /api/capabilities` (which is built from the persisted flap sets) are
  complete from the first second after boot.
- If the gateway boots with an **empty registry** (first boot, or after Identify
  All), it broadcasts `m*v` once at startup so every module on the bus reports
  its version and serial and repopulates the list automatically.
- Saves are written only when the list actually changes (a module appears, is
  provisioned, gets its firmware version recorded, or is deprovisioned) and are
  debounced to limit flash wear.
- The **↻ Identify All** button (or `POST /api/flap/identify`) wipes both the
  in-memory list and the saved file, then broadcasts `m*v` to rebuild from
  scratch.

> [!NOTE]
> On the **first boot after flashing**, the firmware formats the FATFS partition
> (a one-time operation that adds a few seconds to boot — you'll see a
> `formatting now` message on the serial console). Every subsequent boot mounts
> instantly.

---

## Restore on Boot

**New in 3.12.** The gateway can keep a calibration backup in its own flash and
**replay it to every module on every boot**. It exists for walls whose modules lose
or corrupt their EEPROM calibration, or get swapped around: the backup is the source
of truth, and every power cycle puts the wall back exactly as the backup describes.

**Setting it up** (Settings tab → *Restore on Boot*):

1. Create a backup with **Backup Calibration** (or use one you already have — it is
   the same JSON file).
2. **Upload to Gateway**. The file is checked before it is accepted: it must be a
   backup with at least one usable module (a serial number and a parseable dump).
   The card then shows how many modules it holds and when it was created. Uploading
   again replaces it; **Delete Stored Backup** removes it.
3. Tick **Restore calibration on every boot**, set the **delay after boot** (default
   10 s — long enough for the modules to power up and finish their own auto-home),
   and **Save**.

**Run Restore Now** replays the stored backup immediately, without a reboot, which is
also the way to test a freshly uploaded file.

**What a run does**, in order:

- **Waits** out the delay. The bus is already locked at this point.
- **Writes** each module in turn. First an `mXW` frame by serial number carrying the
  home offset, steps per revolution and (firmware v31+) the flap set — which also
  clears the module's flap map — then a pause for the module to finish that erase,
  then **every map entry as its own short `m<id>w<i>:<p>` frame**, paced, exactly as
  the calibration wizard writes them. The map is deliberately not sent inside the
  `mXW`: a module writes each entry to EEPROM as it parses it and cannot keep up with
  a long frame at line speed, so entries vanish and the module goes deaf for several
  seconds (measured on v31 firmware: a 434-byte frame left 20 of 42 entries). If the
  backup's **ID** for that serial differs from the one the gateway knows, the module
  is re-provisioned (`mXI`) between those two steps and given time to restart.
- **Verifies** each module: its EEPROM is read back (`mXA` by serial on firmware
  v25+, `mXD` on v15+, `m<id>d` on older modules) and compared field by field — home
  offset, steps per revolution, every flap position, and the flap set when both sides
  have one. A module that differs or does not answer is written once more and read
  back again; after that the verdict stands. A re-provisioned module is given time to
  restart before it is asked anything.
- **Homes** the whole wall (`m*h`), so every reel re-homes against its restored
  calibration.

**While it runs, nothing else touches the bus.** Every REST endpoint that would send a
frame — display, home, calibrate, provisioning, dumps, diagnostics, raw sends and
batches, quiet-time ON — answers `503 {"error":"restore in progress"}`, and MQTT
commands are dropped (the maintenance switch still works). The dashboard shows a red
border and a banner with the phase and progress, and the Settings card shows the
detail. Read-only endpoints, settings, the bus monitor, the status page and OTA keep
working, so you can watch the run, or **cancel** it. The gateway's own background
bus traffic (the flap-set trickle, stale-module probes, the quiet-time schedule)
pauses too.

**A flap set is only restored when it is self-consistent** — the character set must
be exactly `flapCount` long. A backup taken from a read-back that lost its tail can
carry `flapCount: 64` with three characters, and restoring that would write the
truncated set into the module; such an entry restores the calibration and leaves the
module's flap set alone. The gateway now also refuses to *record* an inconsistent tail
from a module's `A` reply (it is treated as "not reported"), so new backups and
`/api/capabilities` never carry one.

**It always finishes.** Every wait is bounded: a module that never answers is
counted as *not answering* and the run moves on, so a missing or unplugged module
can never leave the gateway locked. When it ends, the card reports how many modules
were verified, mismatched, not answering, or skipped (an entry without a serial or
with a dump the gateway could not parse), and `GET /api/restore` carries the same
numbers. A restore that cannot even start — the setting is on but no usable backup is
stored — is logged and skipped **without** locking anything.

The backup lives in the FATFS partition (`/restore.bak`), written via a temp file and
rename like the module list, so an interrupted upload cannot corrupt a good copy; it
survives OTA firmware updates. The setting and delay are in NVS with the other
configuration.

---

## Split-Flap Protocol

All bus frames are ASCII starting with `m`. On the wire, frames are newline-terminated — but you don't have to manage that yourself: the gateway normalizes framing for every send path (bus monitor, REST, MQTT), adding or stripping the trailing newline as needed and trimming any junk past a complete command. The one frame it intentionally sends *without* a terminator is the direct version query `m<id>v` (a gateway turnaround workaround — the module accepts either form). A **Raw** option bypasses all of this for debugging. See the note under the command table for details.

### Commands (gateway → modules)

| Frame | Description |
|---|---|
| `m<id>-<char>\n` | Show character (e.g. `m5-A\n`) |
| `m<id>+<index>\n` | Show flap by index 0–63 (firmware v7+) |
| `m<id>h\n` | Home the module |
| `m<id>c\n` | Calibrate (measure steps/rev) |
| `m<id>v` | Query firmware version — **sent without a trailing newline** (see note below) |
| `m<id>d\n` | Dump EEPROM configuration |
| `m<id>A\n` | Combined all-fields dump — version + EEPROM in one reply (firmware v25+) |
| `m<id>o<n>\n` | Set home offset (steps past Hall trigger to flap 0) |
| `m<id>t<n>\n` | Set total steps per revolution |
| `m<id>s<n>\n` | Nudge forward n steps and add to home offset |
| `m<id>g<n>\n` | Go to raw step position n |
| `m<id>w<i>:<p>\n` | Write calibrated position p for flap index i |
| `m<id>a<n>\n` | Set auto-home flag (1=home on boot, 0=restore saved position) |
| `m<id>e\n` | Erase calibrated flap position map |
| `m<id>i<n>\n` | Set module ID to n |
| `m<id>N<count>:<chars>\n` | Configure flap count (1–64) and/or character set; both parts optional and independent (firmware v31+) |
| `m<id>R\n` | Reset — erase stored ID, return to unprovisioned (firmware v9+) |
| `m<id>F\n` | Factory reset EEPROM defaults (preserves module ID) |
| `m*h\n` | Broadcast home (all modules) |
| `m*N<count>:<chars>\n` | Broadcast flap-set config — set a whole panel at once (firmware v31+) |
| `m*v\n` / `m*v<lo>-<hi>\n` | Broadcast version query (all modules, or an ID range; firmware v25+ for the range) |
| `m*A\n` / `m*A<lo>-<hi>\n` | Broadcast combined all-fields dump (staggered; prefer ranged batches — each reply is long; firmware v25+) |
| `mXI<sn>:<id>\n` | Assign ID to module by serial number |
| `mXH<sn>\n` | Home module by serial number |
| `mXD<sn>\n` | Dump EEPROM by serial number (firmware v15+) |
| `mXA<sn>\n` | Combined all-fields dump by serial number (firmware v25+) |
| `mXN<sn>:<count>:<chars>\n` | Configure flap set by serial number (firmware v31+) |
| `mXF<sn>\n` | Factory reset by serial number |
| `mXW<sn>:<offset>:<steps>:<map>[:<flapCount>:<flapChars>]\n` | Restore EEPROM to module by serial number; the optional flap-set tail (firmware v31+) round-trips an `A` dump |

> **Framing and sanitization are handled for you.** Whether a frame comes from the bus monitor, `POST /api/rs485/send`, or the MQTT `splitflap/send` topic, the gateway normalizes it at a single transmit choke point. It (1) strips any trailing CR/LF you supplied, (2) **trims anything past a complete, well-formed known command** — so `m4vDSassa` is sent as `m4v` rather than relying on the module to ignore the junk — and (3) re-adds exactly one `\n` terminator, so `m5-A` and `m5-A\n` behave identically and a payload command like `m9o2832` is terminated for you (which also spares it the module's 50 ms idle-timeout wait). By-serial `mX…` frames (e.g. a long restore map) and any command the gateway doesn't model are passed through unchanged, so a legitimate frame is never truncated. The **one exception** to terminating is a direct numeric-id version query `m<id>v`, which the gateway always ships **without** a terminator. This is **not** a module requirement — the module accepts both `m<id>v` and `m<id>v\n` and answers either; it acts on the `v` byte itself. The bare form works around a **gateway-side** limitation in its half-duplex bus turnaround: a module answers a direct version query synchronously, the instant it parses `v` (a dump, by contrast, assembles its EEPROM string first, so its reply is naturally late enough to be safe), but the gateway's hardware driver-enable keeps it driving the line until the whole frame has clocked out, and its receiver is off while it transmits — so a trailing `\n` would keep the gateway transmitting for one extra byte-time (~1 ms at 9600 baud) *after* the module has already started replying, and the reply's leading bytes would be lost. Shipping `m<id>v` bare lets the gateway release the bus and start listening before the module answers. The **broadcast** `m*v` keeps a newline (the gateway adds it): a wildcard query collects an optional `<lo>-<hi>` ID range and the module fires a *staggered, deferred* reply on the newline (or a 50 ms idle timeout), so there's no turnaround race there.
>
> **Raw bypass (debugging).** To send bytes exactly as typed — no trimming, no terminator changes — enable **Raw** in the bus monitor's Send box, or pass `"raw":true` in the `/api/rs485/send` or `splitflap/send` JSON body. This is the escape hatch for deliberately exercising malformed or experimental frames.

### Responses (modules → gateway)

| Frame | Description |
|---|---|
| `m<id>v:<version>:<moduleId>:<serialNumber>\n` | Firmware version |
| `m<id>:<steps>\n` | Calibration result |
| `m<id>d:<homeOffset>:<stepsPerRev>:<map>\n` | EEPROM dump |
| `m<id>A:<version>:<moduleId>:<serialNumber>:<homeOffset>:<totalSteps>:<autoHome>:<curIndex>:<map>[:<flapCount>:<flapChars>]\n` | Combined all-fields dump (v25+): everything from `v` and `d`, plus the auto-home flag and the live current flap index. Firmware **v31+** appends the configured flap count and character set after the map (`flapChars` is the final field and may itself contain `:`/`,`/`=`); older firmware omits the tail and the gateway's parser ignores it on older boards |
| `mXadv:<serialNumber>\n` | Unprovisioned module advertisement |
| `mXack:<serialNumber>:<assignedId>\n` | Provisioning acknowledgement |

> **The gateway uses the combined `A` command automatically when it's more efficient.** When the Info dialog refreshes a module's full state it normally needs both a version query and a dump (two bus transactions). For a module known to be **firmware v25+**, the gateway issues a single `A` instead — one transaction that returns version, serial, and the full EEPROM dump together. Older modules (or a module whose version isn't known yet) fall back to the classic version-then-dump sequence. This is handled internally via the `/api/flap/all` endpoint; no client change is required.

### Character set (64 flaps, index 0–63)

The split-flap character set is owned by the **module firmware**, not the gateway. When you send `m<id>-<char>`, the gateway transcodes the character from UTF-8 to a single **Windows-1252** byte — so a euro sign or an accented letter (which are multi-byte in UTF-8) maps to exactly one flap — uppercases ASCII letters (**except** the seven lowercase colour codes `r o y g b p w`, which address the colour flaps and are sent as-is), and drops any character with no Windows-1252 representation; the module then maps that byte to the correct flap index. The gateway only deals in flap indices when you explicitly send `m<id>+<index>`. The table below is the module's **default** flap order, provided for reference when interpreting EEPROM dumps:

```
 0  SPACE    1  A    2  B    3  C    4  D    5  E    6  F    7  G
 8  H        9  I   10  J   11  K   12  L   13  M   14  N   15  O
16  P       17  Q   18  R   19  S   20  T   21  U   22  V   23  W
24  X       25  Y   26  Z   27  0   28  1   29  2   30  3   31  4
32  5       33  6   34  7   35  8   36  9   37  !   38  @   39  #
40  $       41  &   42  (   43  )   44  -   45  +   46  =   47  ;
48  q       49  :   50  %   51  '   52  .   53  ,   54  /   55  ?
56  *       57  r   58  o   59  y   60  g   61  b   62  p   63  w
```

Indices 57–63 (`r o y g b p w`) are the **colour flaps** — red, orange, yellow, green, blue, pink, white — addressed by those lowercase letters. The gateway sends them verbatim (it does not uppercase them, unlike ordinary lowercase letters) and renders them as colour swatches in the Live Display and the calibration Character Map.

On **firmware v31+** both the active flap count (1–64) and this character order are **configurable per module** at runtime via the `N` command, and persist in the module's EEPROM. For a v31+ module the Module Info dialog shows a **Flap Set** section with the live values and an inline editor (`POST /api/flap/flapconfig`); a whole panel can be set at once with a broadcast (`id:-1`). The section is shown **only** for v31+ modules — on older firmware it is omitted and the fixed 64-flap default set above is used. The configured count and characters are also reported at the end of the `A` dump and are captured in backups so a restore round-trips them.

The flap character set may use **any character representable in Windows-1252 (CP1252)** — that's standard ASCII plus the euro sign `€`, the Western-European accented letters (`é à è ü ö ä ñ ç ß …`), and a few typographic symbols (curly quotes, en/em dashes, `…`, `™`), so you can, for example, print euro-sign flaps instead of `$` or use accented characters. You type/configure them as normal UTF-8 (in the web UI or JSON); the gateway transcodes to the single-byte Windows-1252 form the bus and modules use, and transcodes back to UTF-8 when reporting the set or the live display. Each glyph occupies one flap, and characters with no Windows-1252 representation (e.g. emoji, non-Latin scripts) are rejected.

---

## REST API

Base URL: `http://<gateway-ip>`
All `POST` endpoints accept `Content-Type: application/json`.

### RS-485 Bus

| Method | Endpoint | Body | Description |
|---|---|---|---|
| `GET` | `/api/rs485/messages` | — | Drain buffered frames (up to 64) |
| `POST` | `/api/rs485/send` | `{"data":"m5-A\n"}` (optional `"raw":true`) | Send raw ASCII frame. Framing/junk is normalized by default; `"raw":true` sends bytes verbatim |
| `POST` | `/api/rs485/batch` | `{"frames":["m00-A\n","m01-B\n",…],"step_ms":15}` | **(v3.0)** Send many frames in one request (each normalized like `/send`); optional `step_ms` (0–100) paces the cascade device-side. Lets a host draw a whole animated page in one HTTP call instead of one request per module. Capped at 512 frames. **(v3.4)** Paced frames are now *queued* and sent by the bus task, so the call returns at once — `200` means **accepted**, not yet on the wire (see [Batch pacing](#batch-pacing-v34)) |

#### Batch pacing (v3.4)

`step_ms` staggers a cascade so the wall animates rather than snapping over at once.
Through v3.2 the handler produced that stagger by **sleeping between frames** — and
it ran on the web task. Because the gateway's HTTP server handles **one connection at
a time**, a paced batch froze the *entire* web UI for the length of the cascade (up to
the old 8 s cap) while further connections piled up in the TCP accept queue.

From v3.4 the handler doesn't sleep. It stamps each frame with a **due time**, hands it
to the RS-485 task — which already wakes every 5 ms — and returns. The cascade looks
the same on the wall; the web server stays responsive throughout. Two consequences for
callers:

- **`200` means *accepted*, not *transmitted*.** The frames are queued; `sent` counts
  frames accepted. Nothing in the response tells you the cascade has finished.
- **The 8 s total-pacing cap is gone**, replaced by a queue depth: **127 paced frames
  in flight**. A frame is sent *immediately* rather than paced when `step_ms` is `0`,
  when the frame is longer than 48 bytes, or when that queue is full — so a cascade of
  more than 127 paced frames loses its stagger past that point (the frames still all
  arrive; they just stop being spaced out). A whole-page redraw is one frame per module,
  so this only bites on walls above 127 modules or on multi-step animations.

### Module Control

| Method | Endpoint | Body | Description |
|---|---|---|---|
| `GET` | `/api/flap/modules` | — | List all known modules |
| `POST` | `/api/flap/char` | `{"id":5,"char":"A"}` | Show character (`id:-1` = all) |
| `POST` | `/api/flap/index` | `{"id":5,"index":1}` | Show flap by index 0–63 |
| `POST` | `/api/flap/text` | `{"text":"HELLO","start":0}` | Send text across sequential modules |
| `POST` | `/api/display/cells` | `{"start":0,"step_ms":15,"cells":[{"ch":"H"},{"color":"red"},{"blank":true},{"skip":true}]}` | **(v3.8)** Set a run of modules in one call, the same contract the Matrix Portal gateway answers. Each cell is one of `ch`/`color`/`blank`/`skip`; `step_ms` (0–100) paces the cascade. **Lenient** — a cell that cannot be shown is skipped, and the response is `{ok,cells,sent,skipped}`; only structural errors 400. See [New in 3.8](#new-in-38) |
| `POST` | `/api/flap/home` | `{"id":5}` | Home module (`id:-1` = all) |
| `POST` | `/api/flap/version` | `{"id":5}` | Query version — waits up to 500ms, returns `{ok,id,ver,sn,stale,lastSeen}` |
| `POST` | `/api/flap/dump` | `{"id":5}` | Fetch EEPROM fresh — waits up to 500ms (1s if SN fallback needed), returns `{ok,id,sn,dump}` |
| `POST` | `/api/flap/all` | `{"id":5}` | Refresh version **and** EEPROM together, returns `{ok,id,ver,sn,dump,autoHome,curIndex,flapCount,flapChars,stale,mode}`. Uses one `A` transaction for v25+ modules (`mode:"A"`), else falls back to version+dump (`mode:"vd"`). `flapCount`/`flapChars` are populated only by firmware v31+ (`flapCount:-99`, `flapChars:""` otherwise) |
| `POST` | `/api/flap/identify` | — | Clear the list (memory + saved) and broadcast `m*v` to re-discover all modules |

### Advanced Module Commands

| Method | Endpoint | Body | Description |
|---|---|---|---|
| `POST` | `/api/flap/calibrate` | `{"id":5}` | Calibrate steps/rev — for a single module, waits up to ~15s for the reel to measure and returns `{ok,id,stepsPerRev}` (`504` on timeout); a broadcast (`id:-1`) is fire-and-forget |
| `POST` | `/api/flap/homeoffset` | `{"id":5,"steps":42}` | Set home offset |
| `POST` | `/api/flap/totalsteps` | `{"id":5,"steps":4096}` | Set total steps per revolution |
| `POST` | `/api/flap/nudge` | `{"id":5,"steps":10}` | Nudge forward n steps |
| `POST` | `/api/flap/goto` | `{"id":5,"step":100}` | Go to raw step position |
| `POST` | `/api/flap/writepos` | `{"id":5,"idx":1,"pos":210}` | Write calibrated position for flap |
| `POST` | `/api/flap/autohome` | `{"id":5,"enable":1}` | Set auto-home on boot |
| `POST` | `/api/flap/flapconfig` | `{"id":5,"flapCount":40,"charSet":" ABC…€é"}` | Configure flap count (1–64) and/or character set (firmware v31+); `flapCount` and `charSet` are independent and optional. `charSet` is UTF-8 and may use any Windows-1252 character (ASCII plus € and Western-European accents). Target by `id` (`id:-1` broadcasts to the whole panel) or by `sn`. No reply — read back with `/api/flap/all` |
| `POST` | `/api/flap/erase` | `{"id":5}` | Erase calibration map |
| `POST` | `/api/flap/factoryreset` | `{"id":5}` | Factory reset EEPROM |
| `POST` | `/api/flap/diag` | `{"id":5}` | Self-diagnostics (fw v26+): returns the stats snapshot `q` inline and starts the Hall sensor test — poll `/api/flap/diag/status` |
| `POST` | `/api/flap/diag/mech` | `{"id":5,"revs":10}` | Start the mechanical self-test (after the Hall test); optional `revs` 5–20 (fw v29+, default 5) |
| `GET` | `/api/flap/diag/status` | — | Poll the active motor test: `{ok,state,kind,...}` (`kind` hall/mech; `state` idle/pending/done/timeout; Hall `code` 0–4, mech `code` 0 OK/1 inconsistent/2 no motion) |

A module running **firmware v26 or newer** shows a 🩺 diagnostics icon in the Modules grid. Clicking it runs three self-tests in order and opens a results modal with plain-language interpretation. The **stats snapshot** (`Q`, instant, no motor) decodes the last reset cause from the RSTFR bits (power-on / brown-out / external / watchdog / software) and reports the boot counter, supply voltage, an EEPROM write-verify result, and the current flap index — flagging a sagging supply, a failed EEPROM verify, or a brown-out/watchdog reset (the supply-voltage check is rail-aware, so a healthy 3.3 V reading is not mistaken for a low 5 V rail). The **Hall sensor self-test** (`T`) then spins the reel ~2 revolutions to check the home sensor, reporting OK or one of stuck-active, stuck-inactive, multiple active regions, or inverted polarity. Finally the **mechanical self-test** (`M`) spins the motor several revolutions and reports OK, *inconsistent* (revolutions varied by more than 5 %, pointing to drag, a weak supply, or a failing driver), or *no motion* — alongside the per-revolution step counts, average magnet width, and motion-gate detail that distinguish a stalled motor from a dead sensor. On firmware v29+ the mechanical test takes a selectable **rotation count (5–20, default 5)**; more rotations catch intermittent faults that a short run misses. The Hall and mechanical tests are motor-driven, so they run as asynchronous jobs the UI polls; the snapshot is shown immediately.

### Provisioning

| Method | Endpoint | Body | Description |
|---|---|---|---|
| `POST` | `/api/flap/provision` | `{"sn":"AABBCCDD","id":5}` | Assign ID by serial number |
| `POST` | `/api/flap/deprovision` | `{"id":5}` | Reset to unprovisioned (`id:-1` = all) |
| `POST` | `/api/flap/homebysn` | `{"sn":"AABBCCDD"}` | Home by serial number |
| `POST` | `/api/flap/dumpbysn` | `{"sn":"AABBCCDD"}` | Dump EEPROM by serial number (fw v15+) |
| `POST` | `/api/flap/factoryresetbysn` | `{"sn":"AABBCCDD"}` | Factory reset by serial number |
| `POST` | `/api/flap/restorebysn` | `{"sn":"...","homeOffset":42,"totalSteps":4096,"map":"0=210,1=320,...","flapCount":40,"charSet":" ABC…","id":5}` | Restore EEPROM by serial number. The optional `flapCount`/`charSet` (firmware v31+) restore the configured flap set so a backup round-trips; omit them to leave the module's flap set unchanged. **(v3.12)** The map is written **entry by entry**: the `mXW` carries offset, steps and flap set (and clears the map), then each entry is scheduled as its own `m<id>w` frame, paced on the RS-485 task, using the optional `id` or the registry's id for that serial. Returns at once with `{ok,entries,perEntry,id,settleMs}` — wait `settleMs` before re-provisioning or reading the module back. With no id known the map goes inline (the old behaviour, which a module may not keep up with) |

When a module acknowledges provisioning, the gateway marks it **provisioning-confirmed** and, after a brief settling delay, queries its firmware version (`m<id>v`) to record the version in the registry. The short delay matters: a version request sent the instant the ack arrives reaches the module before it has settled on its new ID, so no reply comes back; the query is also retried a few times until the version is read. A provisioning-confirmed module is never shown as **legacy** — legacy (v7) modules have no serial number and never acknowledge provisioning, so an ack is definitive proof the module is modern, regardless of whether its version has been read back yet. The Modules grid is always sorted by ID (unprovisioned modules last), so a newly provisioned module slots into its proper place rather than appearing at the end.

#### `/api/flap/version` and `/api/flap/dump` response format

```json
{ "ok": true,  "id": 5, "ver": "12", "sn": "AABBCCDD", "stale": false, "lastSeen": 45231 }
{ "ok": false, "error": "no response from module" }
```

`/api/flap/dump` returns data fetched fresh from the module each call (no cache). On timeout it returns `{ "ok": false, ... }`. The `stale` field is always `false` and retained only for response-shape compatibility. `/api/flap/version` includes `lastSeen`, the milliseconds-since-boot of the most recent module activity.

#### `/api/flap/calibrate` response format

```json
{ "ok": true, "id": 11, "stepsPerRev": 4097 }
{ "ok": false, "error": "No calibration response from module" }
```

For a single module the call blocks while the reel physically measures one revolution (up to ~15s), then returns the measured `stepsPerRev`. The module saves the value to its own EEPROM during calibration; callers typically follow up with `/api/flap/totalsteps` to confirm it. A broadcast (`id:-1`) returns `{ "ok": true, "broadcast": true }` immediately.

#### Module object and `lastSeenEpoch`

Each entry from `/api/flap/modules` includes `lastSeen` (millis-since-boot, resets on reboot) and `lastSeenEpoch` (RTC wall-clock epoch in seconds, which survives reboot; `0` until the clock is set). The UI uses `lastSeenEpoch` to show a human-readable "Last Seen" time. A provisioned module that has responded but reports no `fwVersion` is treated as a **legacy** (firmware v7 or earlier) module.

### Status and Configuration

| Method | Endpoint | Body | Description |
|---|---|---|---|
| `GET` | `/api/status` | — | Uptime, IP, MQTT, RTC time, NTP, heap, maintenance and quiet flags, and **(v3.12)** `restore` — `{state,done,total,startsIn}` of the restore-on-boot run (`state` idle/waiting/writing/verifying/homing/done/failed/cancelled) |
| `GET` | `/api/capabilities` | — | **(v3.7)** What the wall can show: `union` (any module), `common` (every module), per-reel `sets` with the module ids that carry each, the colour flaps present by name, and `assumed`/`unknown` module lists. Answered identically by the Matrix Portal gateway. See [New in 3.7](#new-in-37) |
| `GET` | `/api/maintenance` | — | Returns `{ok,on}` — current maintenance-mode state |
| `POST` | `/api/mqtt/test` | `{"host":"...","port":1883,"user":"...","pass":"..."}` (all optional, defaults to saved config) | Test broker reachability + credentials without touching the live connection |
| `POST` | `/api/maintenance` | `{"on":true}` | Enable/disable maintenance mode (ignores external MQTT commands) |
| `GET` | `/api/quiet` | — | Returns `{ok,on}` — current quiet-time state |
| `POST` | `/api/quiet` | `{"on":true}` | Enable/disable quiet time (flaps stop moving for display updates; reels resync when disabled) |
| `GET` | `/api/quiet/schedule` | — | Returns `{enabled,start,end,days}` — the daily quiet-time schedule (`days` is a bitmask, bit0=Sun … bit6=Sat) |
| `POST` | `/api/quiet/schedule` | `{"enabled":true,"start":"22:00","end":"07:00","days":127}` | Set the schedule. When enabled, quiet time toggles automatically as local time crosses the window (overnight windows supported) |
| `GET` | `/api/companion` | — | Returns `{url,status,tabs,gwTabs}` — the registered [companion app](#companion-app)'s URL, its last reported running status, the tabs it advertised, and **(v3.4)** `gwTabs`, this gateway's own tabs |
| `POST` | `/api/companion` | `{"url":"http://192.168.1.60:8000","status":"Running: Weather","tabs":[{"id":"apps","label":"Apps"}]}` | Register the companion (an empty `url` deregisters it) and heartbeat its status. **(v3.4)** may also advertise `tabs` — the deep links its own UI offers; the reply always carries `gwTabs`. The URL is persisted (debounced); status and tabs are runtime-only |
| `GET` | `/api/companion/settings` | — | **(v3.1)** The companion's stored settings blob (gzipped JSON, `application/gzip`), or `404` if none is stored |
| `PUT` | `/api/companion/settings` | `gzip(minified JSON)` — binary body | **(v3.1)** Store the blob verbatim and atomically (max 64 KB). Returns `{"ok":true,"bytes":N}`. See [Companion Settings Storage](#companion-settings-storage) |
| `GET` | `/api/restore` | — | **(v3.12)** Restore-on-boot: the setting (`enabled`, `delay`), the stored backup (`file.exists/bytes/modules/entries/created`), and the current or last run (`state`, `busy`, `trigger`, `total`, `done`, `okCount`, `mismatch`, `missing`, `skipped`, `startsIn`, `elapsed`, `finishedAgo`, `lastError`). See [Restore on Boot](#restore-on-boot) |
| `PUT` | `/api/restore/backup` | a backup JSON file — raw body | **(v3.12)** Store the backup on the gateway. It is parsed before it is accepted (at least one usable module), then written atomically; a bad file never replaces a good one. Max 256 KB. `409` while a restore runs, `422` with the reason if the file is not a usable backup |
| `DELETE` | `/api/restore/backup` | — | **(v3.12)** Delete the stored backup (`409` while a restore runs) |
| `POST` | `/api/restore/run` | `{"delay":0}` (optional, seconds) | **(v3.12)** Replay the stored backup now. Locks the bus at once; `409` if one is already running, `404` if nothing usable is stored |
| `POST` | `/api/restore/cancel` | — | **(v3.12)** Stop a running restore after its current step (`409` if none is running) |
| `GET` | `/api/config` | — | Current configuration (passwords excluded). Includes `"version"` — the firmware version, e.g. `"3.8.0"`, **(v3.12)** `restoreOnBoot` / `restoreDelay`, and **(v3.13)** `stepMs` — the default per-module cascade pacing a client should use (the companion reads it as its default `step_ms`) |
| `POST` | `/api/config/wifi` | `{"ssid":"...","pass":"..."}` | WiFi credentials |
| `POST` | `/api/config/mqtt` | `{"host":"...","port":1883,"user":"...","pass":"...","prefix":"splitflap"}` | MQTT settings |
| `POST` | `/api/config/rs485` | `{"baud":9600,"dataBits":8,"parity":0,"stopBits":1}` | RS-485 bus parameters |
| `POST` | `/api/config/settings` | `{"posixTZ":"EST5EDT,..."}` or `{"serialDebug":true}` or `{"haEnabled":true}` or `{"otaPassword":"..."}` or `{"restoreOnBoot":true,"restoreDelay":10}` or `{"stepMs":25}` | Timezone, serial debug, Home Assistant integration, OTA password, **(v3.12)** restore-on-boot (enable flag and post-boot delay in seconds, 0–600), or **(v3.13)** the default step pacing in ms (0–100). The gateway stores and reports `stepMs`; it does not pace its own sends by it |

### OTA Firmware Update

| Method | Endpoint | Description |
|---|---|---|
| `GET` | `/ota` | Browser-based firmware upload page |
| `POST` | `/api/ota/upload` | Upload the compiled application image `firmware.bin` (multipart). See [OTA Firmware Updates](#ota-firmware-updates) for which file to use |

---

## OpenAPI Specification

The repository includes `openapi.yaml` — a complete [OpenAPI 3.1](https://spec.openapis.org/oas/v3.1.0) description of every REST endpoint.

### Using with Postman

1. Open Postman → click **Import**
2. Drag `openapi.yaml` into the import window
3. Postman creates a collection with all requests pre-configured
4. Set a **Collection Variable** named `baseUrl` to your gateway's IP, e.g. `http://192.168.1.105`

### Using with other tools

| Tool | How to import |
|---|---|
| **Swagger UI** | Paste at [editor.swagger.io](https://editor.swagger.io) for interactive docs with Try it out |
| **Insomnia** | Import → From File → select `openapi.yaml` |
| **VS Code REST Client** | Use the OpenAPI extension to generate `.http` files |

---

## MQTT

Default topic prefix: **`splitflap`** (configurable in Settings → MQTT).

### Published topics

| Topic | Payload | Description |
|---|---|---|
| `splitflap/rx` | `{"ts":...,"wt":"...","command":"m5-A"}` | Frame received from bus |
| `splitflap/tx` | `{"ts":...,"wt":"...","command":"m5-A"}` | Frame transmitted to bus |
| `splitflap/status` | `{"uptime":...,"rx":...,"tx":...,"rej":...,"modules":...,"time":"...","ntpSynced":true,"heap":...,"minheap":...,"maxblk":...,"frag":...,"rssi":...,"wifi":true,"stk485":...,"stkweb":...,"stknet":...,"stkota":...,"stkrtc":...,"ip":"...","url":"http://.../","version":"...","maintenance":false,"quiet":false}` | Heartbeat with the full `[WDG]` diagnostic set, published once per minute |
| `splitflap/flap/adv` | `"AABBCCDD..."` | Unprovisioned module advertisement |
| `splitflap/flap/ack` | `{"id":5,"sn":"..."}` | Provisioning acknowledgement |
| `splitflap/flap/version` | `{"id":5,"ver":"12","reportedId":5,"sn":"..."}` | Version response |
| `splitflap/flap/calibrated` | `{"id":5,"stepsPerRev":4096}` | Calibration result |
| `splitflap/flap/dump` | `{"id":5,"dump":"..."}` | EEPROM dump response |
| `splitflap/availability` | `online` / `offline` | Gateway availability (retained; `offline` set via MQTT Last Will). Used by Home Assistant |
| `splitflap/display/state` | `HELLO WORLD` | Best-known display contents assembled from tracked flap characters (`?` = unknown). Published on change |
| `splitflap/maintenance/state` | `ON` / `OFF` | Maintenance mode state (Home Assistant switch) |
| `splitflap/quiet/state` | `ON` / `OFF` | Quiet time state (Home Assistant switch) |

> The `availability`, `display/state`, `maintenance/state`, and `quiet/state` topics, plus the Home Assistant discovery configs, are only published when Home Assistant integration is enabled on the Settings tab. The `rx`/`tx`/`status`/`flap/*` topics always publish when MQTT is connected.

### Subscribed topics

| Topic | Payload | Description |
|---|---|---|
| `splitflap/send` | `m9h\n` or `{"data":"m9h\n"}` (optional `"raw":true`) | Send raw ASCII frame to bus. Normalized by default; `"raw":true` sends verbatim |
| `splitflap/flap/set` | `{"id":5,"char":"A"}` | Show character |
| `splitflap/flap/home` | `{"id":5}` | Home module |
| `splitflap/flap/provision` | `{"sn":"AABBCC...","id":5}` | Provision module |
| `splitflap/flap/flapconfig` | `{"id":5,"flapCount":40,"charSet":" ABC…€é"}` | Configure flap count and/or character set (firmware v31+); `charSet` is UTF-8 and may use any Windows-1252 character (ASCII + € + accents). Target by `id` (`id:-1` broadcasts) or `sn`; both fields independent and optional |
| `splitflap/display/set` | `HELLO` | Show a plain string across the display from module 0 (Home Assistant text entity) |
| `splitflap/maintenance/set` | `ON` / `OFF` / `true` / `1` | Set maintenance mode (reachable even while maintenance is on) |
| `splitflap/quiet/set` | `ON` / `OFF` / `true` / `1` | Set quiet time |

### Home Assistant

Enable **Home Assistant integration** on the Settings tab (MQTT must be configured). On connect the gateway publishes retained [MQTT discovery](https://www.home-assistant.io/integrations/mqtt/#mqtt-discovery) configs under `homeassistant/<component>/sfgw_<chip-id>/...`, so Home Assistant auto-creates a single device with:

- a **Display** text entity (set/read the display string),
- **Maintenance Mode** and **Quiet Time** switches,
- diagnostic **sensors** mirroring the `[WDG]` heartbeat — modules, uptime, free/min heap, largest free block, fragmentation %, WiFi signal, frames received/sent, parse rejects, the five per-task stack watermarks, IP address, firmware version, and a clickable **Gateway URL**.

Availability is backed by an MQTT Last Will, so entities are marked unavailable if the gateway drops off. Turning the integration off publishes empty discovery payloads to remove the entities cleanly.

---

## Time Configuration

Select your region in **Settings → Timezone**, optionally set a custom **NTP Server**, and click **Save Time Settings**. Both take effect immediately — no reboot required; the clock re-syncs against the configured server on the next network tick.

The **NTP server** defaults to `pool.ntp.org`. You can point it at a LAN time server (e.g. your router) or an alternative public pool (e.g. `time.google.com`, `time.cloudflare.com`) if you prefer. Leaving the field blank restores the default.

| Region | POSIX TZ string |
|---|---|
| US Eastern (UTC-5/-4) | `EST5EDT,M3.2.0,M11.1.0` |
| US Pacific (UTC-8/-7) | `PST8PDT,M3.2.0,M11.1.0` |
| London (UTC+0/+1) | `GMT0BST,M3.5.0/1,M10.5.0` |
| Paris / Berlin (UTC+1/+2) | `CET-1CEST,M3.5.0,M10.5.0/3` |
| Sydney (UTC+10/+11) | `AEST-10AEDT,M10.1.0,M4.1.0/3` |
| Tokyo (UTC+9) | `JST-9` |

---

## OTA Firmware Updates

After the initial USB flash, all subsequent updates can be done over WiFi.

> **Upgrading from a pre-1.6 version?** The firmware *currently running* is what receives and writes the new image, so the OTA-reliability improvements introduced in 1.6 (PSRAM-backed buffers, AP-drop and MQTT-pause during upload) can't help the upload that *first* installs a 1.6-or-later build — they only take effect once that build is running. On a memory-constrained pre-1.6 build the browser upload may drop near the end (heap exhaustion); this is harmless (the image is written to the inactive partition, so a failed upload leaves your old firmware running and fully functional), but for that first jump it's more reliable to use **espota** or a one-time **USB flash**. Once you're on 1.6 or later, the web updater is reliable. No migration is needed: PSRAM is set up at boot, and your saved settings and module registry carry over (the Home Assistant option simply defaults to off).

### Browser upload (recommended)

1. Build the firmware in VS Code / PlatformIO (`pio run`, or the **Build** button).
   The images land in **`.pio/build/esp32s3_devmodule/`**. (Or download `firmware.bin`
   from the [Releases](https://github.com/avandeputte/SplitFlapGateway/releases) page.)
2. The file to upload is **`firmware.bin`** — the plain application image. **This is the
   only file to upload over OTA.**
3. Open the gateway web UI → **Settings** → click **Open Firmware Updater →**
4. Select `firmware.bin` and click **Upload Firmware**
5. The gateway reboots automatically on success. Confirm the new build by checking the version badge in the header (e.g. **v3.5.0**).

> **Which file?** PlatformIO emits several files in `.pio/build/esp32s3_devmodule/` —
> pick the right one:
>
> | File | Use for OTA? | What it is |
> |---|---|---|
> | `firmware.bin` | ✅ **Yes** | The application image — what the OTA updater writes to the app partition |
> | `firmware.factory.bin` | ❌ No | Full-flash image (bootloader + partitions + app) for a bare-board USB flash at offset 0x0 — **not** an OTA image |
> | `bootloader.bin` | ❌ No | Bootloader; USB flash only |
> | `partitions.bin` | ❌ No | Partition table; USB flash only |
> | `firmware.elf` / `firmware.map` | ❌ No | Debug symbols / linker map — not firmware |
>
> The common mistake is grabbing `firmware.factory.bin`. For OTA you always want the plain `firmware.bin`.

> **Fixed in 3.12.** Before 3.12 the browser upload failed near the end of every full-size
> image: the connection reset at about 1.2–1.3 MB, nothing was flashed, and the board stayed
> on its old firmware. The upload callback added a response header on every received chunk,
> and the web server keeps each of those (as a heap-allocated node) until the response goes
> out, so ~1000 chunks ate ~80 KB of a 100 KB heap. The header is now set once, on the
> response, and a full image uploads in about 10 s with 80 KB of heap to spare. The page also
> waits for the gateway to come back and reports the firmware version it rebooted into.

### Command line (espota)

An alternative to the browser upload that needs no page open. The gateway advertises over
mDNS as `splitflap-gw-<6 hex digits>` (printed at boot; `dns-sd -B _arduino._tcp` lists it):

```bash
# PlatformIO: the esp32s3_ota environment is preconfigured for it
pio run -e esp32s3_ota -t upload                       # upload_port from platformio.ini
pio run -e esp32s3_ota -t upload --upload-port 192.168.1.105
```

```bash
# from .pio/build/esp32s3_devmodule/
python3 -m espota -i splitflap-gw.local -f firmware.bin

# or by IP, with an OTA password set:
python3 -m espota -i 192.168.1.105 -a yourpassword -f firmware.bin
```

> PlatformIO can also push OTA directly via its **Upload** action — set
> `upload_protocol = espota` and `upload_port = splitflap-gw.local` in `platformio.ini`
> (see [SETUP.md ▸ OTA](SETUP.md#10-later-updates-over-wi-fi-ota)).

### If the web update fails — recovery without developer tools

A failed browser upload **never damages the gateway**: the new image is written to the
inactive app slot and only made bootable once the last byte has been verified, so if the
upload stops early the old firmware simply keeps running (you'll see the old version in the
header, and the uptime on the Status tab keeps counting). Nothing to undo. Here are three ways
to get the new firmware on anyway, none of which need PlatformIO, VS Code, or a build
environment. Every release on the
[Releases](https://github.com/avandeputte/SplitFlapGateway/releases) page carries the files
they use.

**1. Try again after a reboot.** Power-cycle the gateway, open `http://<gateway-ip>/ota` in a
fresh tab (close the dashboard and anything else that polls the gateway), and upload
`SplitFlapGateway-<version>.bin` again. Since 3.12 the browser upload is reliable; the one
case that can still fail is the *first* jump **from** a firmware older than 3.12, because it
is the *running* firmware that receives the image — and a freshly rebooted board gives it the
most memory to do that with.

**2. Over Wi-Fi with one small Python script (no USB cable).** This is the route the
gateway's own build tooling uses, and it was never affected by the browser problem. You need
Python 3 ([python.org](https://www.python.org/downloads/) on Windows; already on macOS and
Linux) and one file from Espressif:

1. Download **`espota.py`** from
   <https://raw.githubusercontent.com/espressif/arduino-esp32/master/tools/espota.py>
   (right-click → *Save as…*) into the same folder as the downloaded
   `SplitFlapGateway-<version>.bin`.
2. Find the gateway's IP address on its **Status** tab (or use `splitflap-gw-xxxxxx.local`,
   the name printed on the Status tab's hostname line).
3. In a terminal (Windows: *Command Prompt* or *PowerShell*) in that folder:

   ```bash
   python3 espota.py -i 192.168.1.105 -p 3232 -f SplitFlapGateway-3.12.0.bin
   # Windows: use  python  instead of  python3
   # if you set an OTA password on the Settings tab, add:  -a yourpassword
   ```

   The script prints a progress bar, the gateway verifies the image and reboots, and the
   header shows the new version about 15 seconds later. If it reports *no response from
   device*, a firewall on your computer is blocking the gateway's reply — allow Python
   through it, or use option 3.

**3. Over USB, from a browser (Chrome or Edge).** Nothing to install; this also works on a
gateway that will not boot at all.

1. Connect the gateway's USB-C port to your computer with a **data** cable (many USB-C
   cables are charge-only; if no port appears in step 3, try another cable or port).
2. Put the board in download mode: press and **hold BOOT**, tap **RESET**, release
   **BOOT**.
3. Open <https://espressif.github.io/esptool-js/>, click **Connect**, and choose the port
   named *USB JTAG/serial debug unit* (or *USB Serial*).
4. Add files to flash — **two files, two addresses**, to keep your settings:

   | File (from the release) | Flash address |
   |---|---|
   | `SplitFlapGateway-<version>.bin` | `0x10000` |
   | `boot_app0.bin` | `0xE000` |

   The second, tiny file tells the bootloader to start from the slot you just wrote.
   Without it, a board that had previously updated over the air may keep booting the *other*
   slot — the old firmware — no matter how many times you flash. Your WiFi/MQTT settings,
   the module list, and any stored restore backup all survive this flash.

   *Alternatively*, flash the single **`SplitFlapGateway-<version>.factory.bin`** at
   address **`0x0`**. That is the complete image (bootloader, partition table, boot
   selector and app) and is the right choice for a blank board or one that is thoroughly
   confused — but it **erases the WiFi and MQTT settings**, so afterwards you reconnect
   through the `Split-Flap-GW` fallback access point as on [first boot](#first-boot). The
   module list and stored backup live in a separate flash area and survive either way.
5. Click **Program**, wait for *Leaving…*, then press **RESET** (or unplug and replug).
   Open the dashboard and check the version in the header.

Prefer a terminal over the web flasher? [`esptool`](https://github.com/espressif/esptool)
(`pip install esptool`) does the same:

```bash
esptool --chip esp32s3 write_flash 0x10000 SplitFlapGateway-3.12.0.bin 0xE000 boot_app0.bin
# or, full image (erases settings):
esptool --chip esp32s3 write_flash 0x0 SplitFlapGateway-3.12.0.factory.bin
```

---

## Default Settings

| Setting | Value |
|---|---|
| AP SSID | `Split-Flap-GW` |
| AP Password | `12345678` |
| RS-485 baud | 9600 |
| MQTT port | 1883 |
| MQTT topic prefix | `splitflap` |
| NTP server | `pool.ntp.org` |
| Timezone | UTC |
| Serial debug | Disabled |
| OTA password | None |

---

## License

[Creative Commons Attribution-NonCommercial-ShareAlike 4.0 International (CC BY-NC-SA 4.0)](https://creativecommons.org/licenses/by-nc-sa/4.0/)

You are free to share and adapt this project for non-commercial purposes, as long as you give appropriate credit and distribute any derivatives under the same license.

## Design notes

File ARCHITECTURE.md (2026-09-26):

# Architecture Notes

This document captures the reasoning behind non-obvious design decisions in the
Split-Flap Gateway firmware, so future maintainers (including future-you) don't
have to re-derive them.

## Task model

The firmware runs five FreeRTOS tasks plus `loop()`:

| Task | Core | Priority | Responsibility |
|---|---|---|---|
| `taskRS485` | 0 | 3 | Byte accumulator for the RS-485 bus |
| `taskRTC` | 0 | 2 | Reads the PCF85063 RTC every second -- and nothing else (see below) |
| `taskWeb` | 0 | 2 | `server.handleClient()` loop |
| `taskNetwork` | 1 | 1 | WiFi/MQTT/NTP, status publishing, registry persistence, the quiet-time schedule |
| `taskOTA` | 1 | 1 | `ArduinoOTA.handle()` every 100ms |
| `loop()` | — | — | Watchdog check every 30s |

Shared state is protected by four mutexes: `sfMutex` (module registry),
`msgMutex` (RS-485 ring buffer), `timeMutex` (time formatting — newlib time
functions are not thread-safe), and `mqttQMutex` (MQTT outbound queue). Only
`taskNetwork` ever calls `mqtt.publish()`.

## Watchdog

`loop()` checks each task's heartbeat timestamp every 30 seconds and reboots if
any task has gone silent past its threshold (RS485/Net = 30s, Web = 120s). It
also force-reboots if free heap drops below 20KB. Thresholds differ because the
web task can legitimately block for several seconds while streaming a large page
to a slow client.

Two boot-time guards prevent false reboots during startup:

- **60-second grace period.** Stall detection is skipped for the first 60s of
  uptime. The one-time FATFS format (first boot after flashing) and WiFi/MQTT
  bring-up happen in this window and can briefly skew task scheduling; rebooting
  then would be a false positive. The low-heap emergency check still runs during
  the grace period.
- **Future-timestamp guard.** Each heartbeat check treats a timestamp "in the
  future" (`wdg > now`, possible only from transient boot-time skew) as healthy,
  rather than letting the unsigned subtraction underflow to a huge value that
  would look like a 49-day stall.

## Web server: why the synchronous `WebServer`, not `ESPAsyncWebServer`

The firmware uses the Espressif-maintained synchronous `WebServer` that ships
with the ESP32 Arduino core. This was a deliberate choice, re-evaluated after a
`Web=0` watchdog stall was observed (the web task blocked inside
`server.handleClient()` on a half-open client socket — a known limitation of the
synchronous server when a browser opens a speculative TCP connection and never
completes the request).

`ESPAsyncWebServer` would eliminate that specific stall, but it carries its own
trade-offs that, for a single-user home-network gateway, were judged not worth
the risk:

- **Third-party maintenance risk.** The async server is a community library
  (the actively maintained fork is currently `mathieucarbou/ESPAsyncWebServer`),
  not part of the Espressif core. The sync `WebServer` ships with the core and
  has a guaranteed maintenance path.
- **No blocking allowed in handlers.** Async callbacks run on the lwIP (`tiT`)
  thread. The `/api/flap/version` and `/api/flap/dump` endpoints currently wait
  up to ~500ms–1s for a module to reply over RS-485. That pattern is illegal in
  async and would require redesigning those two endpoints to return immediately
  and have the client poll (or a deferred-response mechanism).
- **Tighter stack / thread-safety constraints.** Running on the lwIP thread
  means limited stack for the large `char` buffers used in handlers, and every
  access to shared state (`sfModules`, etc.) crosses a thread boundary —
  mutex mistakes become hard crashes rather than recoverable stalls.
- **Heavier, less predictable heap use.** Async buffers responses and manages
  its own allocations; per-connection transient footprint is larger. After the
  effort spent getting heap dead-stable (see below), the predictability of the
  sync server is a feature.
- **The streaming response needs rework either way.** `handleRoot` streams the
  UI as ~154 `sendContent()` chunks; async uses a pull-based chunked-response
  callback, a different control flow.

### Mitigation in place

Rather than migrate, `taskWeb` proactively force-closes any client connection
that lingers longer than 8 seconds (`c.stop()`), reaping the half-open
speculative sockets (Chrome/Safari behavior) that cause the wedge before they
can block the send path. The 120s web watchdog remains as the safety net. A
watchdog reboot in this scenario is *correct recovery* — a task wedged in a
kernel syscall cannot be interrupted from itself — and the device survived 6.5
hours before the single observed stall, recovering cleanly.

**Revisit trigger:** if `Web=0` stalls recur despite the 8s reaper, the async
migration becomes justified. The real work there is redesigning the two blocking
endpoints, not the boilerplate.

### The corollary: never block `taskWeb` (v3.4)

Choosing the one-connection-at-a-time server makes a rule out of what would
otherwise be a style preference: **a handler that blocks blocks the whole web UI.**
Two handlers were violating it, and both produced real failures.

**1. Batch pacing (`/api/rs485/batch`).** The handler produced its `step_ms` stagger
with `delay()` between frames. That is a cascade-length sleep — up to the old 8 s cap —
inside a handler, during which nothing else could be served and further connections
piled up in lwIP's accept queue holding TCP window buffers. On a companion driving
animations this is not an edge case; it is the steady state.

The fix moves the *pacing* off `taskWeb` without moving the *work*: the handler stamps
each frame with a due time (`millis()` timebase), pushes it into a small PSRAM ring
(`TxQItem`, `rs485.h`), and returns. `taskRS485` — which already wakes every 5 ms —
drains whatever is due on each tick. The 5 ms tick quantises `step_ms`, which is 5–30 ms
anyway, so the cascade is visually identical.

The ring is **SPSC**: `taskWeb` is the only producer, `taskRS485` the only consumer,
guarded by `txQMutex`. That mutex is deliberately **released before** `rs485Send` runs
(which takes `txMutex`), so the two locks are never nested and the producer is never
stalled for the duration of a send. Due-time comparison is wrap-safe
(`(int32_t)(now - dueMs) >= 0`), so the 49-day `millis()` rollover is a non-event.

The trade-offs are deliberate and worth knowing. `200` now means **accepted**, not
transmitted. The ring holds 127 frames (one slot kept empty as the full/empty
discriminator); a frame that cannot be queued — `step_ms == 0`, longer than
`TXQ_FRAME_MAX` (48 B), or a full ring — is sent **inline, immediately**. So a cascade
longer than 127 paced frames stops being paced past that point, and an over-long frame
jumps ahead of frames still waiting in the ring. Display/index/home frames are all far
under 48 bytes and a whole-page redraw is one frame per module, so neither case arises
below a 127-module wall; both are graceful (the frames still go out) rather than errors.
If the PSRAM allocation fails, `txQueue` is `NULL`, every enqueue returns false, and the
endpoint degrades to sending everything inline.

**2. The module list (`/api/flap/modules`).** It sent one `sendContent()` per module.
Each of those can block on a slow client up to the socket timeout (3 s), so the total
scaled with module count: ~41 modules × 3 s crosses the 120 s web-stall threshold, the
supervisor sees `Web=0` and **reboots the gateway**. The bug was latent for as long as
it was because it simply cannot fire below ~40 modules. The response is now coalesced
into ~1400 B chunks, feeds `wdgWebMs` on each flush, and bails out early once
`server.client().connected()` goes false.

The general lesson, worth applying to any new handler: if it can sleep, wait on a
module, or scale its send count with the size of the registry, it belongs on another
task or in a chunked loop that feeds the watchdog.

## Multi-language UI (v3.5)

The dashboard ships every language in **one firmware image**. That is only affordable
because the translatable text is a small slice of the page: 109 KB of HTML+CSS+JS, but
only ~10 KB of it is English *words* (~310 strings). Duplicating the **page** per
language would cost ~109 KB each; duplicating the **text** costs ~1.5 KB gzipped each.
So there is one page, plus one gzipped dictionary per language in flash, and the browser
fetches only the one it needs (`GET /lang/<code>`).

**English is the page.** It is not a dictionary — it is the text already in the markup.
That makes the default path free (no fetch, no JS dependency), makes English the natural
per-key fallback, and means a failed fetch degrades to English rather than to a broken
page. A dictionary may therefore be *partial*: the en-GB dictionary is 7 entries, because
only 7 strings differ.

**The key is the English text**, not an invented id. That is safe here only because the
UI has no homographs -- every string that repeats, or appears under two different tags,
means the same thing in both places. It buys a lot: the markup needs **no `data-i18n`
tagging at all**, so 200+ HTML strings are translated without touching the page.

Two runtime mechanisms, because neither alone is sufficient:

- **A DOM walk + `MutationObserver`** translates *text nodes*. The observer is the part
  that matters: most of this UI's content (module cards, the flap map, the wizard) is
  built by JS *after* load, and a one-shot walk would miss all of it.
- **`t("...")`** translates messages the JS *composes* -- `"Error: " + e`. A DOM walk only
  ever sees the finished string ("Error: Bad JSON"), which is not a key, so these have to
  be wrapped at the source. `t()` looks up the *trimmed* key and re-attaches the edge
  whitespace, so `t("Error: ")` works and translators never have to preserve a trailing
  space.

Re-running the walk is harmless: a translated node is no longer a key, so it is a no-op.

**Wrapping is context-aware, and that is not fussiness.** Only literals inside a
`.textContent` assignment, `confirm()` or `alert()` are wrapped -- because JS strings that
*look* like prose are routinely code. `'nav a'` is a `querySelector`; `'HOME         '` is
a bus-monitor decode label whose padding keeps the log's monospace columns aligned. A
naive "wrap every prose-looking literal" pass would have translated both and broken the
page. For the same reason the runtime **skips `#log` entirely**: the monitor renders
protocol, not chrome.

Language, highest priority first:

1. **`?lang=fr`** -- lets the companion request a language for an embedded view *without*
   touching the user's own preference, so it is deliberately **not** persisted.
2. **The Settings override** (`localStorage`).
3. **`navigator.languages`** -- the "Auto" default. This is why the gateway stores **no
   language state at all**: no config field, no NVS write, no API. It mirrors what the UI
   already does with the light/dark theme, which follows the OS with no setting.
4. **English.**

The one subtlety worth protecting (there is a test for it): an `en-US` browser must
resolve to the **base** English, not to `en-GB` merely because that is the only other
`"en"` on the list. Resolution is therefore exact-match, then base-language, then any
variant -- with `en` itself on the list as the base. See `tools/i18n_test.js`.

`Content-Encoding: gzip` **is** correct on `/lang/<code>`, and is exactly what must
*not* be sent for the companion settings blob: here the gzip is a transfer encoding of
JSON that the browser inflates before `fetch().json()` sees it; there, the gzip *is* the
payload.

## Companion URL: why it is persisted on a debounce (v3.4)

`cfg.companionUrl` is the one config value written by a *machine* rather than a person,
on a heartbeat, and that changes what "persist on change" costs. Point two companions at
one gateway and each re-registers its own URL every ~30 s, so the value flips back and
forth forever — and the original `saveConfig()`-on-change turned that into an NVS write
every ~30 s for the life of the device. This was observed in the wild, not theorised.

So the URL is applied to RAM immediately (the dashboard's companion tab is live at once)
while the **flash write waits for the value to hold still** for
`COMPANION_SAVE_DEBOUNCE_MS` (120 s), with the clock **restarting on every change**. The
debounce is deliberately longer than a heartbeat, which means a *contested* URL is never
written to flash at all — the correct outcome, since nothing durable should be committed
for a value two clients are still arguing over. A single genuine change persists after
two quiet minutes, and a companion re-registers within a heartbeat of any reboot, so
nothing is actually lost by not persisting a contested one.

The companion's **status** and advertised **tabs** are runtime-only for the same reason,
one step further: they are re-sent on every heartbeat, so there is nothing a flash write
would buy.

## Memory management

The gateway is intended to run for weeks unattended, so heap stability is
critical. Several issues were found and fixed:

- **`rtcFormatTime` `setenv` leak (root cause of the long-standing drain).**
  The function originally called `setenv("TZ", ...)` twice per invocation to
  convert stored-UTC RTC time to local time. On ESP32 newlib, repeated `setenv`
  leaks heap (~66 bytes/pair). Called every 10s by `mqttPublishStatus` and on
  every browser status poll, this produced the observed ~132 bytes/30s constant
  decline. **Fix:** `TZ` is set exactly once at boot (`loadConfig`) and again
  only when the timezone changes (`handleApiConfigSettings`). `rtcFormatTime`
  now computes the UTC epoch manually (a portable days-since-1970 algorithm,
  since `timegm()` is not exposed in ESP32 newlib) and applies the local zone
  with `localtime_r()` — no per-call environment manipulation.
- **`JsonDocument` in hot paths.** ArduinoJson 7's `JsonDocument` allocates its
  pool from the heap on every call; on ESP32's `dlmalloc` this fragments and
  trends `getFreeHeap()` downward. `mqttPublishMsg` (every RS-485 frame),
  `mqttPublishStatus` (every 10s) and `handleApiStatus` (every browser poll)
  were converted to `snprintf` into stack buffers. The remaining `JsonDocument`
  uses are in on-demand REST handlers, where fragmentation impact is negligible.
- **Per-message `String` allocations** in `ringDrain` and `sfParseResponse`
  were replaced with stack `char` arrays.
- **`handleApiModules`** reserves its output `String` up front
  (`out.reserve(sfModuleCount * 220)`) to avoid realloc churn, and
  `loadUnprovisioned` browser polling was slowed from 3s to 10s (it was doubling
  the `handleApiModules` call rate).

After these fixes, heap holds stable (observed ~139KB steady-state) with only
normal allocator sawtooth that recovers on traffic.

## Sticky module persistence

The known-module registry survives reboots so the dashboard isn't empty after a
power cycle. Storage uses a **FATFS file** (`/modules.dat`) in the FATFS
partition that already exists in the default "16M Flash (3MB APP/9.9MB FATFS)"
scheme -- deliberately NOT a custom partition table or an enlarged NVS region,
to keep flashing simple and avoid erasing config on partition changes.

- Only durable fields are stored (id, serial, provisioned, fwVersion,
  lastSeenEpoch). The transient display state and on-demand EEPROM dumps are not
  persisted.
- `lastSeenEpoch` is an RTC wall-clock timestamp (not `millis()`, which resets),
  so "last seen N hours ago" is meaningful across reboots. Entries older than
  `MODULE_STALE_SECS` (6h) are pruned on load; at runtime (once a minute) a stale
  entry is first **probed** with a version query and dropped only if it stays
  silent past a grace window, so a quiet-but-present module is never purged. The
  runtime probes are spaced out and sent in bounded batches -- a module answers a
  bare version query synchronously, so firing them back-to-back would make each
  reply collide with the next probe on the half-duplex bus.
- Writes are atomic: the file is written to `/modules.dat.tmp` then renamed over
  the live file, so a crash mid-write can't corrupt the existing good copy.
- Saves are debounced (5s) and only triggered when the registry actually changes
  (new module, provision, deprovision), limiting flash wear.
- "Identify All" (`POST /api/flap/identify`) wipes both the in-memory list and
  the file, then broadcasts `m*v` to rebuild from scratch.

`MAX_MODULES` is 255, covering module IDs 0-254 (ID 255 is reserved as the
empty-slot / unprovisioned sentinel). With the EEPROM dump cache removed from
the in-RAM struct (dumps are now fetched on demand), each `SFModule` is ~48
bytes, so the full registry is ~12 KB of RAM and the persisted file is ~9 KB --
both comfortable on the 8 MB-PSRAM / 512 KB-SRAM ESP32-S3. The largest transient
cost is the `handleApiModules` JSON response (~33 KB heap String at 255
modules), which is `reserve()`d up front and freed immediately after each send.

A deliberate design point: the RS-485 **frame buffers** (`MSG_MAX_BYTES` = 256
for the monitor ring, `TX_MAX_BYTES` = 768 for outbound frames, `MQTT_BUF_SIZE`
= 768) are sized by the **largest single frame**, not by module count. The
worst-case frame is a full 64-flap EEPROM restore (`mXW<sn>:<offset>:<steps>:<map>`,
~620 bytes; on firmware v31+ an optional `:<flapCount>:<flapChars>` tail adds up
to ~67 bytes, still well inside `TX_MAX_BYTES`) -- a frame always targets one
module, so raising the module ceiling from 200 to 255 does not change them.
Three-digit IDs (vs two) add at most ~1 byte to a handful of commands, still far
inside `TX_MAX_BYTES`. These buffers were sized for the frame, and the frame is
what bounds them.

## Companion settings blob (v3.1)

The companion app parks its settings on the gateway (`GET`/`PUT
/api/companion/settings`) so its container can be stateless. The gateway is a
**dumb blob store**: the payload is `gzip(minified JSON)` whose schema belongs
entirely to the companion, and the firmware stores the bytes verbatim, hands them
back byte-for-byte, and never parses them. That boundary is the whole point --
the companion's schema can evolve freely without ever touching firmware.

It reuses the FATFS partition and the same temp-file-then-rename atomicity as the
module registry above (`/compset.gz`, via `/compset.tmp`), so an interrupted
upload cannot corrupt a good copy. The blob is capped at 64 KB; real ones are
1-2 KB, and the companion debounces its writes, so flash wear is negligible.
Because it lives on FATFS rather than in the app partition, it survives OTA.

The non-obvious part is **receiving the body at all**. The synchronous
`WebServer` copies a non-form request body into a `String` via its `char*`
constructor, so `server.arg("plain")` stops at the first NUL byte -- and a gzip
stream carries one at offset 3 (the FLG header byte). A 127-byte blob would
arrive as 3 bytes. So the PUT is registered with the four-argument
`server.on(uri, HTTP_PUT, fn, ufn)` overload: supplying that upload callback is
what makes `WebServer` route the request down its **raw** path
(`RequestHandler::canRaw()` is true whenever a handler has a `ufn` and isn't a
GET), streaming the body to the callback in `HTTP_RAW_BUFLEN` (1436 B) chunks
that we append straight to the temp file. The final handler then sends the
response, reading a status the raw callback left behind.

Two consequences worth remembering: the raw callback **cannot stop** the server's
read loop, so a request that fails validation early (too large, no filesystem)
must keep draining chunks and simply drop them, or the response never reaches the
client; and the response is deliberately served as `application/gzip` **without**
`Content-Encoding: gzip`, because those bytes are the payload rather than a
transfer encoding of it -- declaring the encoding would make HTTP clients
transparently gunzip the body, leaving the companion to decompress plain JSON.

## Time handling

The RTC stores UTC. Local time is derived at format time using the configured
POSIX TZ string (DST-aware). The `timeMutex` serialises all time-formatting
calls because newlib's time functions and the `TZ` environment are process-wide
and not thread-safe. The NTP server is configurable (default `pool.ntp.org`);
`configTime` is always called with a zero offset so the system clock is UTC and
`mktime` acts as `timegm`, avoiding double-offset bugs.

## Diagnostics

The periodic `[WDG]` line and the boot banner are the primary field-debugging
surface. Boot prints `esp_reset_reason()` (distinguishing a firmware `PANIC`
from a `BROWNOUT` power fault from a clean `POWERON`) plus a heap/PSRAM/flash
snapshot. The `[WDG]` line, emitted every 30 s, carries free heap, minimum-ever
heap, largest allocatable block and a derived fragmentation %, per-task stack
high-water marks (the early-warning signal for the stack-canary crash class),
bus RX/TX counters, a parse-reject counter (rising = bus collisions or noise),
WiFi RSSI, and MQTT state. Stall reboots name the offending task and its age;
low-heap reboots log the heap value. None of this requires the serial-debug
toggle -- it is always on, because the situations it diagnoses (unexpected
reboots, slow memory leaks, bus corruption) are exactly the ones where you
cannot reproduce on demand.

## Protocol note: dump-by-serial vs dump-by-id

`/api/flap/dump` prefers the serial-number command `mXD<sn>` only when the
module reports firmware **v15 or newer**, because `mXD` does not exist in older
firmware. For older modules (or if the SN-based request times out) it falls back
to the ID-based `m<id>d`. This keeps the EEPROM inspector working across all
firmware versions.

## Module self-diagnostics

The 🩺 diagnostics action (module firmware v26+) runs three tests in the fixed
order **Q → T → M**, reusing the existing reply-capture machinery rather than
adding a parallel path. The **`Q` stats snapshot** is instant and captured
synchronously in the request handler, exactly like an EEPROM dump: arm a wait
slot, send the frame, spin on a ready flag with the web-task watchdog touched.
The **`T` Hall self-test** and **`M` mechanical test** are motor-driven (~2 and
~6+ revolutions), so they share a single async job — only one motor test is ever
in flight. The browser sequences them: `POST /api/flap/diag` returns the
snapshot and starts `T`; once the poll reports `T` done it calls
`POST /api/flap/diag/mech` to start `M`. The `M` job deadline scales with the
requested rotation count (5–20 on firmware v29+), because the motor time does.

The reply frames (`m<id>Q:…`, `m<id>T:…`, `m<id>M:…`) are parsed in
`sfParseResponse` alongside `v`/`d`/`A`, into per-test capture globals; the `M`
parser keeps the trailing comma-separated per-rotation list as its greedy last
field. `GET /api/flap/diag/status` is consume-on-read (it reports `done` once,
then `idle`), so the UI poller is built to match: one request in flight at a
time (self-scheduling, not a fixed interval), firing its terminal callback
exactly once, with a generation counter that cancels any stale poller left by a
new run or a closed modal. That combination is what stops a late `idle` read
from clobbering a result the module actually returned.

## Restore on boot: why the gateway locks itself (v3.12)

`restore.cpp` replays a stored calibration backup to every module at boot (or on
`POST /api/restore/run`). Three decisions there are worth recording.

**The lock is global, and it is held from `setup()`.** The user's requirement was that
nothing else be processed until the restore completes, and the reason is physical: a
display frame, a home, or a companion batch arriving mid-restore would interleave with
`mXW` frames on the half-duplex bus and with the read-back waits. So `restoreBusy()` is
true from the moment `restoreInit()` arms the run -- before any task is running -- and
`webInit()` wraps every bus-touching handler in `BUSGATED()`, which answers 503 instead of
running it. MQTT commands are dropped in `mqttCallback`. This is deliberately broader than
maintenance mode (which only gates MQTT): here the gateway's own REST API is refused too.
The gateway's *internal* bus traffic pauses as well (the flap-set trickle, stale probes,
the quiet schedule), for the reason below.

**Verification captures ANY reply.** The restore addresses modules by serial and does not
know which id a read-back will carry (the backup's id may differ from the module's current
one, and it may just have been re-provisioned). So it arms the shared dump slot with
`SF_WAIT_ANY`, and `sfParseResponse` records the answering id and, for an `A` reply, its
serial in `gDump.gotId` / `gDump.gotSN`. That wildcard is safe only because the run has the
bus to itself -- which is why the trickle's `m<id>A` is paused: an unsolicited `A` landing
in a verify window would be read as the wrong module's EEPROM.

**It cannot hang.** "Block everything" is only acceptable if the block is guaranteed to
end. Every wait is bounded (`RESTORE_VERIFY_TIMEOUT_MS` x `RESTORE_VERIFY_TRIES`, plus one
repair round), a silent module is counted as missing rather than waited for, a cancel is
honoured between steps, and a run that cannot even start (no usable file) logs and does
NOT lock. A re-provisioned module, which restarts and is deaf for `MODULE_POSTPROV_VER_MS`
plus its staggered start-up, is given a `readyAt` deadline rather than a retry storm.

The backup is parsed with ArduinoJson into **PSRAM** (a 64-module backup is ~45 KB, and
the internal heap is what WiFi lives on) and the document stays alive for the whole run,
so the write and verify phases iterate the same entries. The upload is validated by the
same parser before it is renamed over the live file, so a bad upload never replaces a
good backup.

### What the modules taught the restore (v3.12.0, first field run)

Two things the first runs on a real wall showed, both now encoded in `restore.cpp`:

- **A module cannot ingest a long `mXW` at line speed.** It writes each map entry to
  EEPROM as it parses it, its receive buffer overflows, entries vanish, and it goes deaf
  for ~6 s. Measured on v31 firmware: a 434-byte frame left 20 of 42 entries. So the map
  is not sent inline. `mXW` carries offset, steps and the flap set (and clears the map),
  `RESTORE_MXW_SETTLE_MS` covers the erase, then each entry goes as its own short
  `m<id>w<i>:<p>` frame `RESTORE_ENTRY_GAP_MS` apart -- the wizard's frames. Verification
  waits `RESTORE_SETTLE_MS` after a module's last write. A 15-module wall restores and
  verifies in ~33 s.
- **A truncated `A` tail must not be believed.** A long `A` reply sometimes loses its end
  in transit, parsing as `64:` plus a handful of characters. Recording that poisoned the
  registry and the backups, and a restore then wrote the truncated set into the module.
  `sfParseResponse` now treats a tail whose character count does not match its flap
  count as "not reported", and the restore neither writes nor verifies such a set.

## Module registry: permanent, re-queried, never pruned (v3.12)

Until v3.12 a module not heard from in `MODULE_STALE_SECS` was probed and, if silent,
dropped -- at load and once a minute. That made `/api/capabilities` incomplete after a
reboot until every module had been asked again, and it forgot modules that were merely
displaying a static message (modules only speak when addressed). The registry is now
permanent: `sfModulesLoad` never prunes by age, and `sfModulesPruneStale` is a periodic
RE-QUERY -- a bare version query, `MODULE_PROBE_BATCH` per cycle, spaced so the instant
replies do not collide -- that refreshes the record and notices a swapped or re-flashed
module. After `MODULE_PROBE_MAX_TRIES` unanswered queries the module is left alone for
`MODULE_REPROBE_BACKOFF_MS` and then asked again. Only Identify All, De-provision, or a
corrupt record removes an entry. The persisted flap sets are therefore always present
at boot, which is what makes capabilities complete from the first second.

## Browser OTA: never add a header per chunk (v3.12)

The multipart upload callback (`handleOTAUpload`) ran once per received chunk, and it began
with `server.sendHeader("Access-Control-Allow-Origin", "*")`. In the ESP32 core 3.x
`WebServer::sendHeader()` appends a heap-allocated `RequestArgument` (a node plus two
Strings) to a linked list that is only released when the response is sent -- after the whole
body. A 1.48 MB image arrives in ~1000 chunks of 1436 bytes, so ~1000 nodes accumulated:
~80 KB of a ~100 KB heap, min-free heap under 1 KB, and the connection reset at 1.2-1.3 MB
on every full-size image, at any upload rate (a rate-limited upload died the same way). The
symptom was easy to misread as the well-known "receive buffers pile up" story, which the
release notes had blamed for two versions. The header now goes on the response, once. Rule
for every chunked callback (upload or raw): no `sendHeader()`, no allocation that outlives
the chunk. A full image now uploads in ~10 s with ~80 KB of heap free throughout.

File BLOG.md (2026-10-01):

# Three Projects, One Goal: Making Split-Flap Displays Easier to Build, Run and Enjoy

If you've ever wanted to build one of those beautiful mechanical split-flap displays you see in train stations and airports, you've probably come across [Adam G Makes](https://www.youtube.com/@AdamGMakes) on YouTube. His [split-flap display project](https://youtu.be/-C8_AtxEEQc?si=Gym5wikeFH2vUNRm) is a masterpiece of DIY engineering — each character cell is a compact, self-contained module built around an ATtiny1616 microcontroller, driven by a stepper motor with a Hall sensor for positioning, and connected to a shared RS-485 bus. The result is a display that looks and sounds exactly like the real thing.

The hardware is excellent. But as the community around this project has grown, three separate limitations have emerged that make the display harder to scale, maintain, and actually *enjoy* than it needs to be. This post is about three independent projects that each tackle one of those limitations — and why all three were built with great care not to break anything that already works.

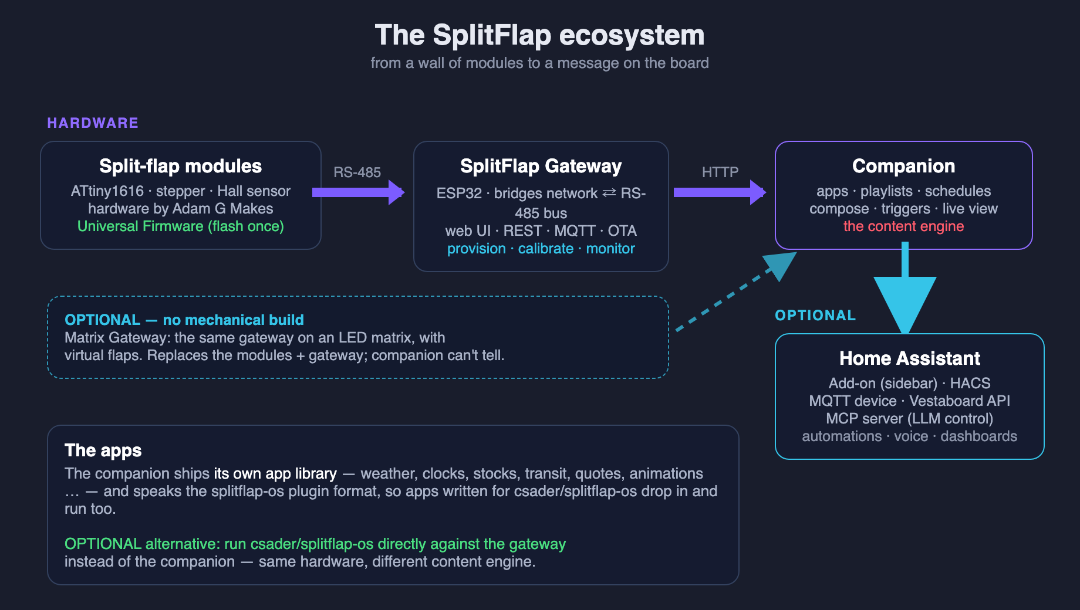
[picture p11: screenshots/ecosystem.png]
The SplitFlap ecosystem: modules, gateway, companion
  
*The three pieces and how they connect: modules on an RS-485 bus, a gateway that bridges the bus to the network, and a companion that decides what to show.*

> Everything below, and a great deal more, is documented step by step in the **[SplitFlap wiki](https://splitflap.iothing.net/docs/)** — start with the [Quick Start](https://splitflap.iothing.net/docs/Quick-Start/) if you'd rather build than read.

---

## Limitation One: One Firmware Per Module

In Adam's original firmware, each module's bus address — the ID that tells it which RS-485 commands to respond to — is **hardcoded directly into the firmware binary**. Module 1 has a different firmware than module 5, which has a different firmware than module 38. Every single module requires its own edit-compile-and-flash cycle before it can be installed.

For a small display with a handful of modules this is merely tedious. For a larger display with dozens of modules it becomes a genuine logistical burden. Each module must be individually flashed with a customised binary before installation. Swap a module, and you flash again. Rearrange the physical layout, and you're back to the IDE.

### The Solution: Universal Firmware with Runtime Provisioning

The [SplitFlapUniversalFirmware](https://github.com/avandeputte/SplitFlapUniversalFirmware) solves this by eliminating the hardcoded ID entirely. You still flash each module yourself — this is a DIY project after all — but every module runs the **exact same firmware binary**. Flash it once per module, and you're done. Identity is assigned at runtime through provisioning, not at compile time. As a side note, this also means Adam could, if he ever wanted to, sell pre-flashed modules — since the firmware is universal, a module can come straight out of the box, get plugged into the bus, and be provisioned on the spot without anyone ever touching the IDE.

Every ATtiny1616 microcontroller has a factory-programmed, globally unique 10-byte serial number burned into its silicon. The universal firmware reads this at boot and uses it as the module's permanent identity. When a module powers up without an assigned bus ID, it broadcasts its serial number on the RS-485 bus every 10–15 seconds (with randomised intervals to avoid collisions when many modules power on simultaneously).

To claim a module, a host system sends a provisioning command:

```
mXIA3F24C0018E7D29B3F01:38\n
```

This tells the module with that serial number to assign itself bus ID 38, write it to EEPROM, and stop advertising. From that moment on it behaves exactly like any other module on the bus. To physically identify which module corresponds to which serial number before assigning, a home-by-serial command spins only the matching module:

```
mXHA3F24C0018E7D29B3F01\n
```

One binary. Flash once per module, provision once, done.

### It Grew Into More Than an ID

Once every module had a permanent identity, other things became possible that the original firmware couldn't offer:

- **Backup and restore by serial number.** A module's entire calibration can be read out in one command and written back later — to the same module, or to a replacement — because the serial number, not the bus position, is what identifies it.
- **A configurable flap set.** The flap count and the character printed on each flap are stored per module. Print a reel with `É`, `Ö` or `Ñ` on it, or a shorter reel without punctuation, tell the module, and text still lands on the right flap.
- **Built-in self-diagnostics.** A module can report its supply voltage, reset cause and EEPROM health without moving, test its own Hall sensor, and spin its reel several times to detect missed steps — so when a cell misbehaves you can tell power, sensor and motor apart without opening it.
- **Automatic Hall-sensor polarity detection**, a brown-out detector, and a watchdog, so a module that gets into trouble recovers on its own.

### Backward Compatibility Was Non-Negotiable

The universal firmware was built with full backward compatibility as a hard requirement. Every command from Adam's original protocol works exactly as before — the same syntax, the same responses, the same timing. Projects already built on the original firmware continue to work unchanged.

A good example is [splitflap-os](https://github.com/csader/splitflap-os) by csader — a polished web-based control interface with a large library of apps (weather, stocks, sports scores, word clock, news headlines and more), playlists, live preview, calibration tools, and Home Assistant integration via MQTT. It runs on the Raspberry Pi alongside the display and speaks the same RS-485 protocol. The universal firmware adds provisioning commands without touching anything splitflap-os uses — both work together without any modifications, and splitflap-os has since built provisioning into its own UI.

---

## Limitation Two: A Computer Inside the Display

In the original project setup, the RS-485 bus connects directly to a Raspberry Pi that lives physically inside or alongside the display assembly. The Pi is the brains of the operation — it drives the bus, runs whatever software controls the display, and handles all the application logic.

On the surface that sounds fine. In practice it means you have a full Linux computer embedded in your display. That computer needs to be maintained. OS updates, security patches, SSH access, a filesystem that can corrupt if you pull the power at the wrong moment. If something goes wrong with the Pi, your display stops working. For a decorative display you just want to run reliably for years, that's a surprising amount of ongoing responsibility.

### The Solution: A Microcontroller That Does One Job

The [Split-Flap Gateway](https://github.com/avandeputte/SplitFlapGateway) replaces the Raspberry Pi with a single low-cost microcontroller board — the [Waveshare ESP32-S3-RS485-CAN](https://www.amazon.com/dp/B0FNCWZ3D1) — that does exactly one thing: bridge the RS-485 bus to your WiFi network. No operating system to patch. No filesystem to corrupt. The firmware lives in flash memory, boots in under a second, and runs indefinitely without intervention.

The "heavy stuff" — the UI, the automation logic, the integration with other systems — runs somewhere you already own and maintain. Your PC, your NAS, a home automation server. You're not adding a new computer to maintain; you're connecting to infrastructure you already have.

Beyond simply replacing the Raspberry Pi, the gateway opens up integration possibilities that didn't exist before. In the original project the only way to talk to the display is the RS-485 bus protocol — which means anything that wants to control the display needs to be physically wired to the bus and speak that low-level protocol directly. The gateway changes that completely. By bridging the bus to WiFi and exposing it through REST and MQTT, any device on your network — a phone, a laptop, a home automation controller, a cloud service — can send a character to the display with a single HTTP request or MQTT message, no knowledge of RS-485 required.

The gateway exposes the bus through three interfaces simultaneously:

**A web UI** served directly from the ESP32. Open a browser, navigate to the gateway's address, and you have a full dashboard: every known module with its current character and firmware version, a live wall that mirrors what the display is showing, provisioning tools, a guided calibration wizard, a live bus monitor with every RS-485 frame decoded, and settings. It speaks fourteen languages, follows your light or dark theme, and there is no app to install and no account to create.

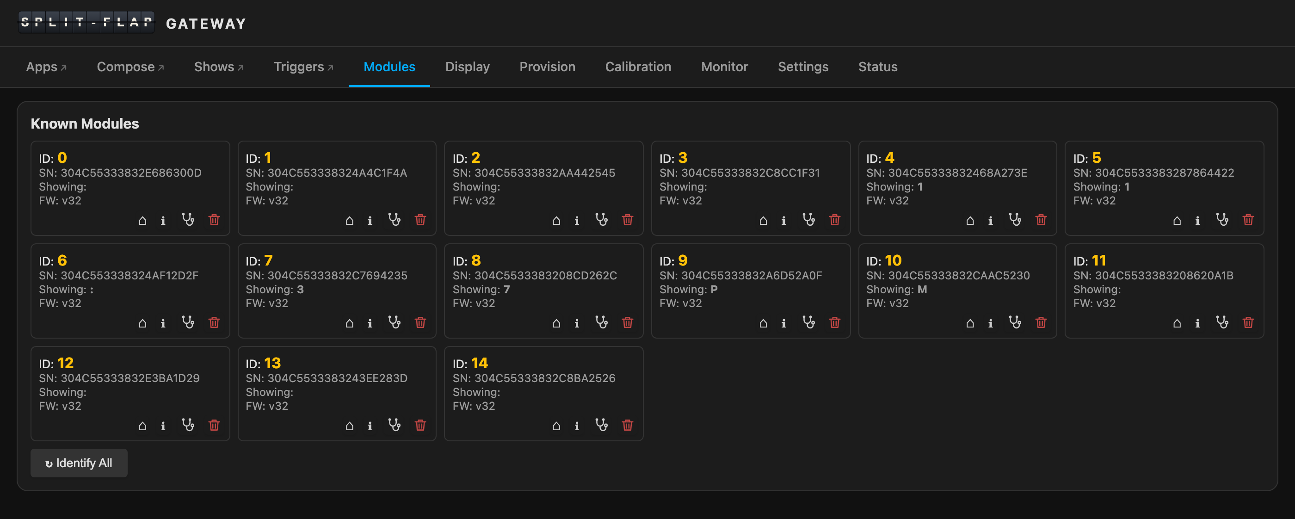
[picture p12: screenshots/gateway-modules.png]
Modules tab — every known module with its ID, serial number, current character and firmware version
  
*Modules tab — every known module at a glance. Each card has icons to home it, inspect its EEPROM, run its self-diagnostics, or take a destructive action*

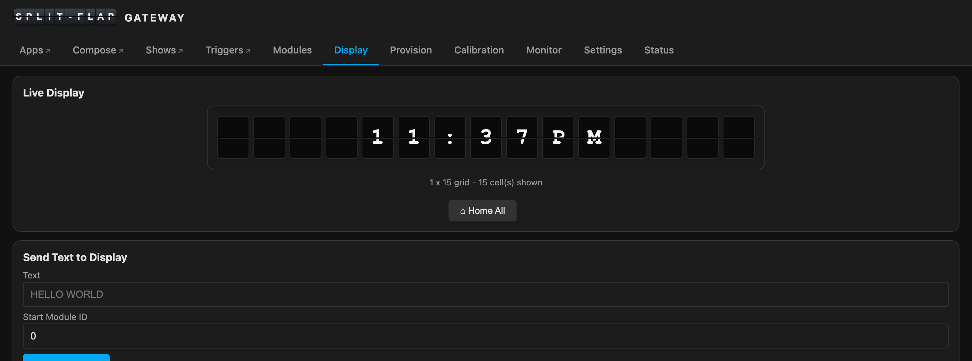
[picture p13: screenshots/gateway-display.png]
Display tab — the live wall, and boxes to send text or a single character
  
*Display tab — a live rendering of the wall, and boxes to push a string across the modules or address a single one*

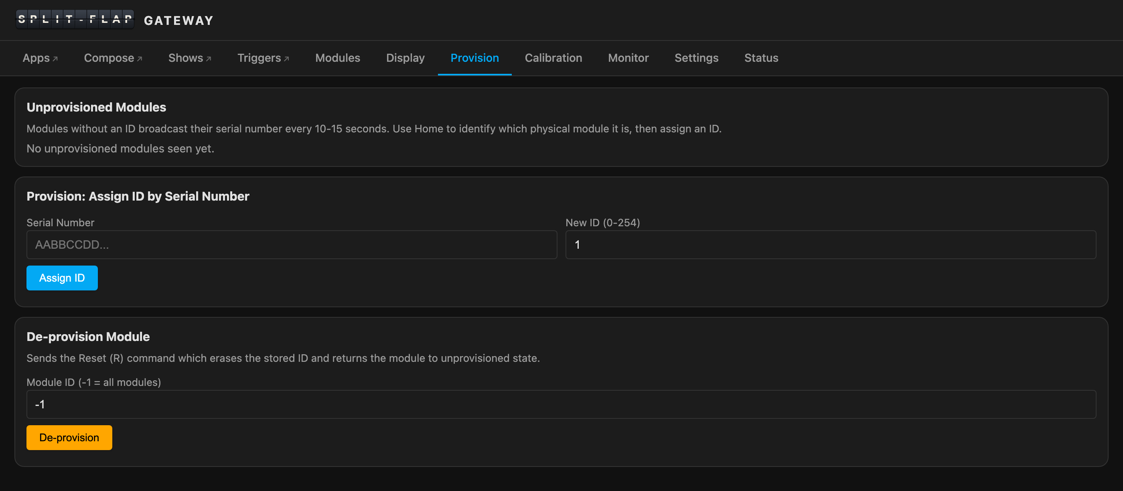
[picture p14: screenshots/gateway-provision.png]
Provision tab — modules advertising their serial numbers, ready to be identified and assigned
  
*Provision tab — unprovisioned modules appear by themselves; home one to see which physical tile it is, then assign an ID*

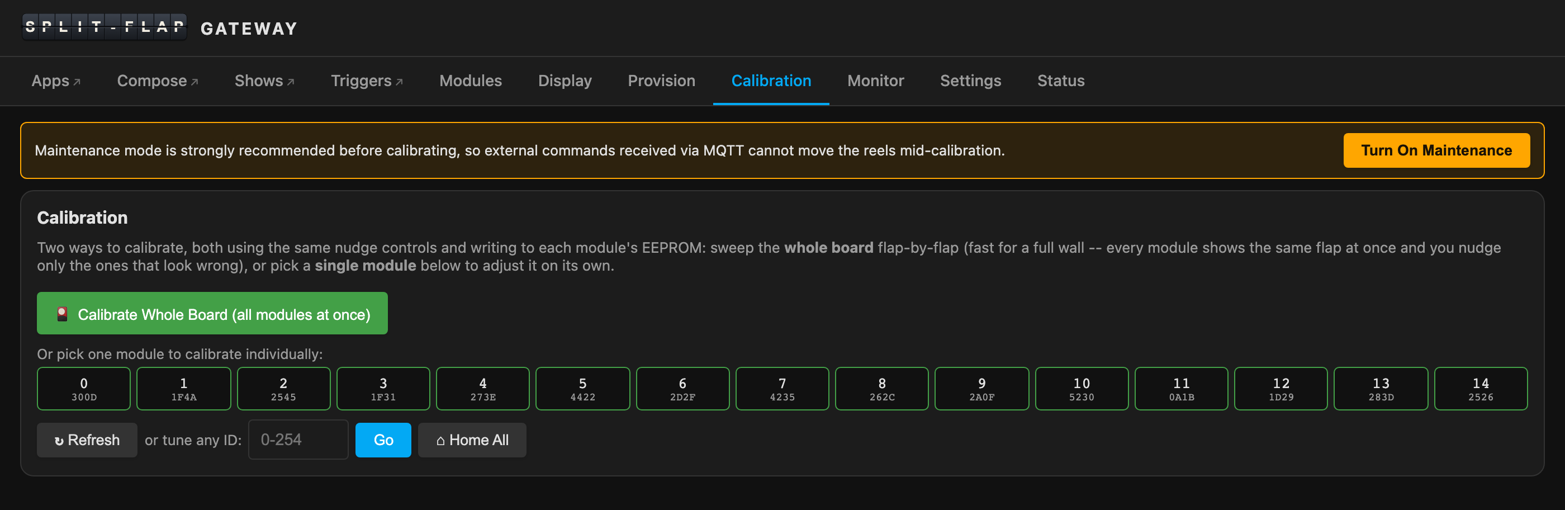
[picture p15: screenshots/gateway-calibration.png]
Calibration tab — the module picker laid out like the wall
  
*Calibration tab — pick a module from a grid laid out like your wall, measure its steps, nudge its home position, tune any flap, or let the wizard walk every flap for you*

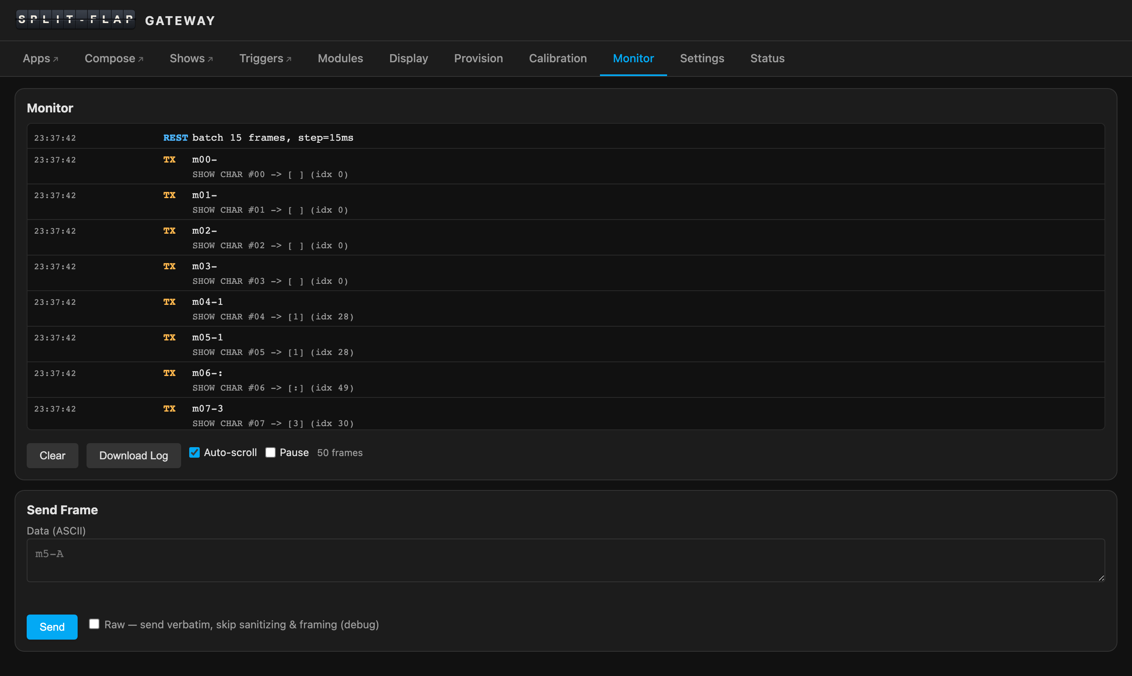
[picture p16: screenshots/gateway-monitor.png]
Bus Monitor — live RS-485 traffic, decoded
  
*Bus Monitor — every RS-485 frame in both directions, decoded into plain language, with timestamps in your browser's local time*

**A REST API** with more than fifty endpoints covering every operation — sending characters, homing, calibrating, running self-diagnostics, provisioning by serial number, backing up and restoring calibration, and reading or updating configuration. One call, `GET /api/capabilities`, tells a client exactly what characters this particular wall can show. An [OpenAPI specification](https://github.com/avandeputte/SplitFlapGateway/blob/main/openapi.yaml) is included so you can import the whole API into Postman or Swagger UI with a single file.

**MQTT integration** using the `splitflap/` topic prefix. Every frame that travels in either direction on the RS-485 bus is published. Module events each get their own topic. Turn on Home Assistant discovery and the gateway appears there as a device, with a text entity for the display, switches for maintenance and quiet time, and diagnostic sensors.

### It Looks After the Wall

A few things the gateway does on its own, because a display you want to forget about has to be able to look after itself:

- **A permanent module registry.** It remembers every module it has ever met — identity, firmware, flap set — across reboots, so the wall is fully known the second the gateway comes up.
- **Quiet time.** A schedule, a switch, or a Home Assistant automation blanks the wall for the night and puts back what it was showing in the morning.
- **Maintenance mode**, so home-automation traffic can't fight you while you calibrate.
- **Over-the-air updates** from the browser. After the first USB flash, you never need a cable again.

### Also Backward Compatible

The gateway speaks the same RS-485 protocol as everything else in this ecosystem. It works with Adam's original hardcoded firmware, with the universal firmware, and with existing tools like splitflap-os, which can drive it over MQTT. If you're already running splitflap-os on a Raspberry Pi and want to experiment with the gateway, the display protocol is identical — no changes to splitflap-os required.

---

## Limitation Three: What Do You Actually Show?

With the first two projects in place you have a wall that provisions and calibrates itself from a browser and takes an HTTP request from anywhere. And then you sit in front of it and realise that a split-flap display with nothing on it is furniture. The hard part was never sending a character. It's *deciding* what to show — the weather when you're leaving, the next train, the score of the game, a word clock at other times, a birthday message when someone walks in — and doing that every day, for years, without anyone having to think about it.

splitflap-os solves that for the Raspberry Pi setup, and solves it well. But it's built around living inside the display, next to the bus, and that is exactly the arrangement the gateway set out to remove.

### The Solution: A Content Engine That Lives Where You Do

The [Split-Flap Companion](https://github.com/avandeputte/SplitFlapGatewayCompanion) is the third piece. It's a web app that runs on a machine you already have — a Raspberry Pi, a NAS, a home server, or as a Home Assistant app — and drives the wall over the gateway's REST API. The gateway can put any character on any flap; the companion's job is to know which ones.

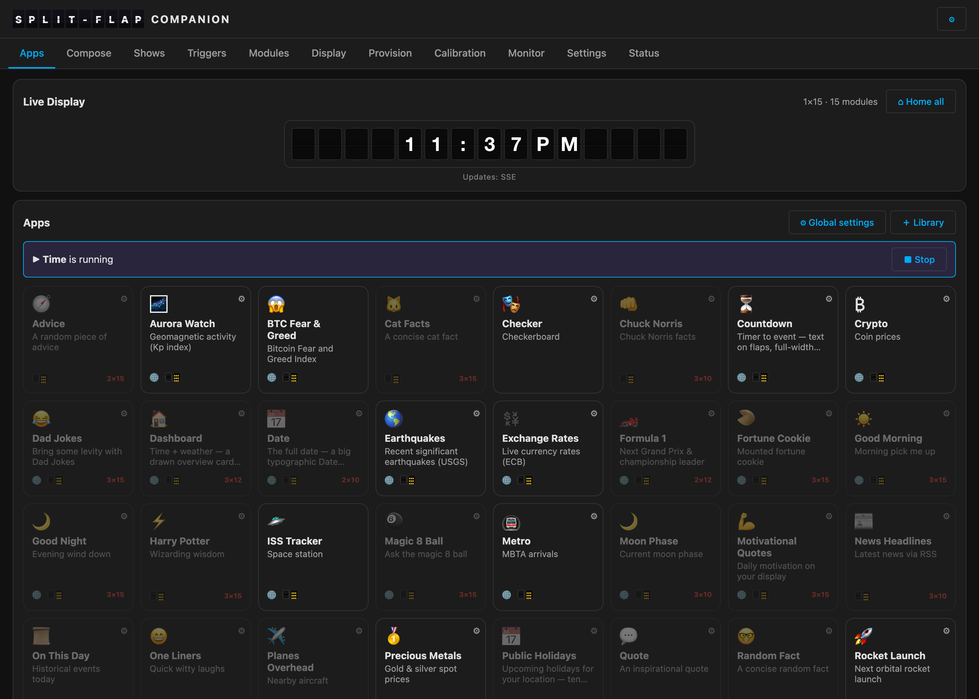
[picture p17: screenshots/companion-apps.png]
The companion's Apps tab — a playlist running, the live board mirroring the wall, and the app library
  
*The companion's Apps tab — the live board mirrors the wall (here the Time app is running), one tap runs an app, and the gateway's own tabs sit right in the companion's nav*

What's in it:

- **Apps.** A library of ready-to-run apps — weather, clocks, a word clock, stocks and crypto, transit arrivals, sports scores, the ISS passing overhead, countdowns, quotes, animations, and many more — each with its own settings. The library keeps growing, and you can add or remove apps from inside the companion.
- **Compose.** A click-to-type grid that mirrors your wall: click a cell, type, and each keystroke lands on that module. Colour tiles, every transition style, and a button to push the whole grid.
- **Playlists**, on the Shows tab. Sequence apps and messages with a duration for each, save, loop. The same app can appear twice with different settings — weather for two cities in two languages, say. A multiview splits the wall into zones that each run their own thing.
- **Schedules.** Run an app or a playlist in time-of-day windows per weekday, plus quiet hours.
- **Triggers.** Apps that watch for something — a game starting, the ISS coming over, a weather change — and briefly interrupt the display, then let it resume.
- **A live view** of the wall, updated in real time, and a Home All button.

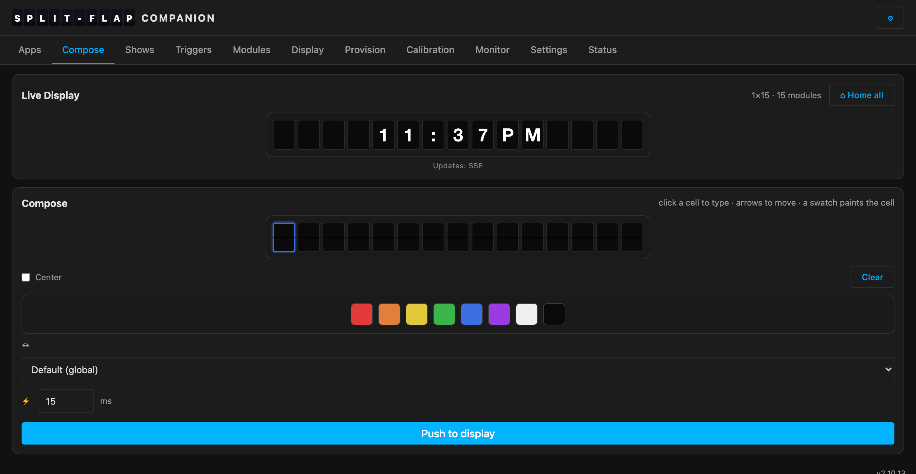
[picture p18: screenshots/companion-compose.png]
Compose — the click-to-type grid
  
*Compose — click a cell, type, and it lands on the wall*

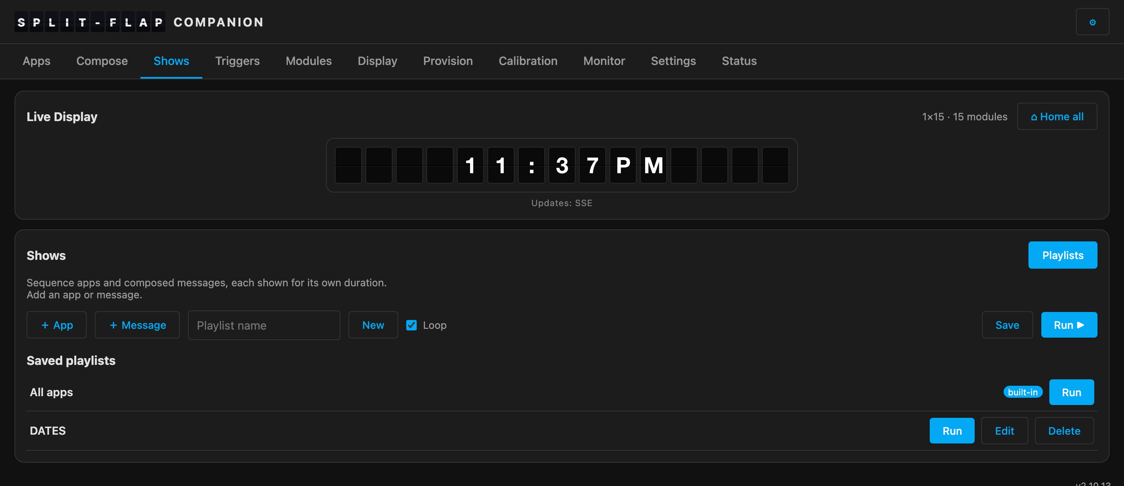
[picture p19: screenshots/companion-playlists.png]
Playlists — editing a saved playlist
  
*Shows — sequence apps and messages into playlists, each entry with its own settings and duration*

### It Speaks Your Language — and Your Reel's

A global language setting (US, UK and Australian English plus the major Western-European languages) changes the translated words, the date order, the number format and the clock in every app that adapts, and currency and public holidays follow your *location*. Both can be overridden per app and per playlist entry, so one playlist can show Paris in French and Berlin in German back to back.

Whether those words can actually be shown depends on what's printed on your flaps, and this is where the three projects fit together. The gateway asks every module what its reel carries, and answers the companion's one question — *what can this wall show?* — in one call. The companion writes text the way a person writes it and lets the wall decide the case: uppercase on a physical split-flap, lowercase and accents on a display that has them. An app never needs to know which kind of wall it is talking to.

### It Fits Into What You Already Run

The companion plugs into **Home Assistant** three ways — as a sidebar app, as a HACS integration with real entities, and as an MQTT device — so the wall becomes a target for automations, voice, and dashboards. Two more doors are plain HTTP and need no Home Assistant at all:

- It **answers the Vestaboard Local API**, so the large pool of software written for that commercial split-flap display — integrations, Node-RED flows, scripts — drives your wall unchanged.
- It exposes the display as **MCP tools**, so an LLM such as Claude can read the board and drive it in plain language: *"put standup on the board for two minutes, then put back what was playing."*

One companion can drive **several walls**, each with its own apps, playlists and settings. And it keeps its own configuration *in the gateway's flash*, so the container is stateless: destroy it, start another one on a different machine, and it picks up where it left off.

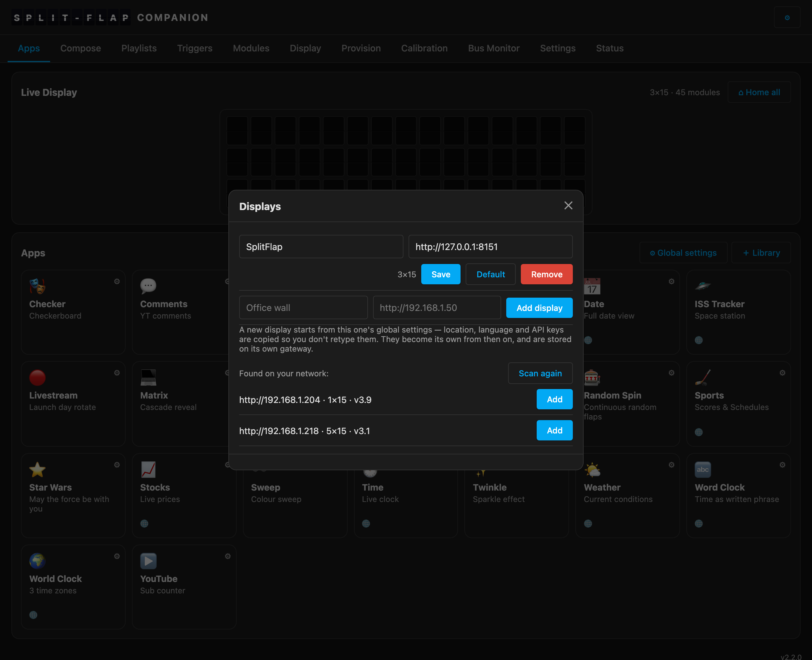
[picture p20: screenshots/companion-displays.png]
The Displays dialog — a network scan has found two gateways
  
*Several walls from one companion — a network scan finds the gateways, one tap adds them*

### Also Backward Compatible

The companion's apps use the **splitflap-os plugin format** — a manifest plus a small Python file or a data file — and run on a behaviour-identical plugin runtime. Any app written for splitflap-os drops in unchanged, and an app you write for the companion is an app for splitflap-os too. The two projects share a format rather than compete for one.

---

## No Mechanical Build? Same Software, Different Wall

Because the companion only ever talks to a gateway, and the gateway's job is to *be* a wall of modules, two more boards offer the same thing with **virtual** flaps: the [Matrix Gateway](https://github.com/avandeputte/MatrixPortalGateway) on an RGB LED matrix, and the [LCD Gateway](https://github.com/avandeputte/SplitFlapGatewayLCD) on a 10.1" touchscreen. They are their own firmware, but they speak the same split-flap protocol (with a few capabilities a drawn flap can add, such as lowercase and accents) and present the same web UI and REST API, so each replaces the modules *and* the gateway in one board. The companion can't tell the difference, and the same app spells its text on a physical wall and draws a richer panel on the emulated one.

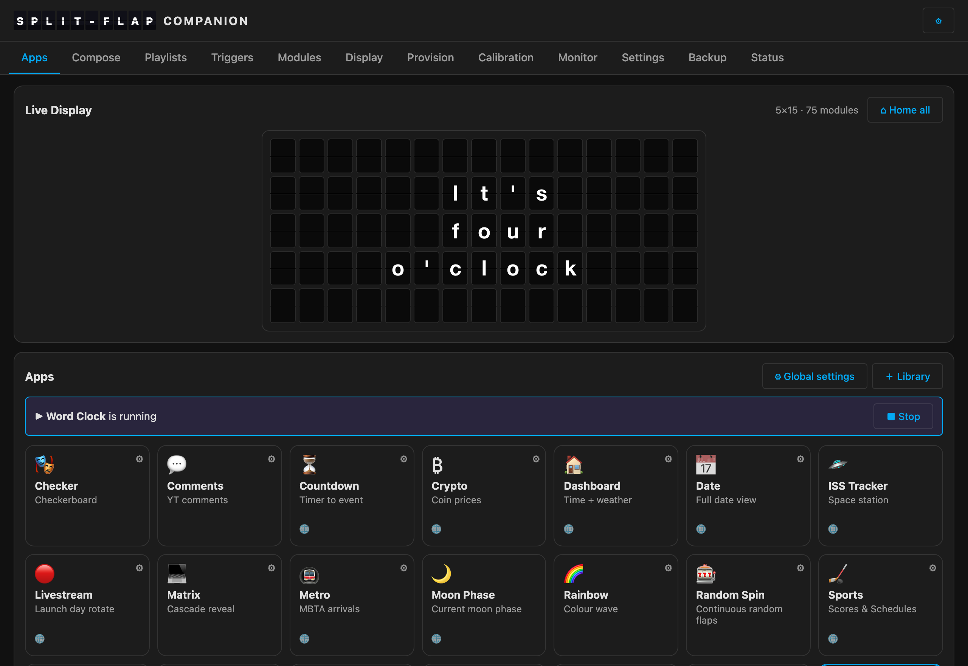
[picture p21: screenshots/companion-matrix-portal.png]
The Word Clock app on a Matrix Gateway
  
*The same Word Clock app, at the same minute, on an LED-matrix wall*

It's a good way to try the whole stack before cutting a single flap — and a good display in its own right.

---

## Three Projects, Independently Useful

These are three separate projects that solve three different problems. They work best together, and the wiki's [Quick Start](https://splitflap.iothing.net/docs/Quick-Start/) walks that path — but none of them depends on the others:

- **Universal firmware without the gateway** — keep the Raspberry Pi, provision from splitflap-os or the included terminal tool, and you still get one binary for all modules, backup and restore by serial number, custom flap sets and self-diagnostics.

- **Gateway without the universal firmware** — happy with Adam's original hardcoded firmware and just want the Pi out of the display? The gateway works perfectly: send characters, home, calibrate, monitor the bus, control the wall from anywhere on your network. You just won't have provisioning, since the original firmware doesn't support it.

- **Gateway without the companion** — drive it by hand from its own web UI, from your own scripts against the REST API, from Home Assistant over MQTT, or from splitflap-os.

- **All three together** — flash once, provision and calibrate from a browser, and let the companion decide what the wall shows, when, and in which language, from wherever you already run things.

Every viable mix is compared, with a feature grid, in the wiki's [Choosing a Configuration](https://splitflap.iothing.net/docs/Choosing-a-Configuration/).

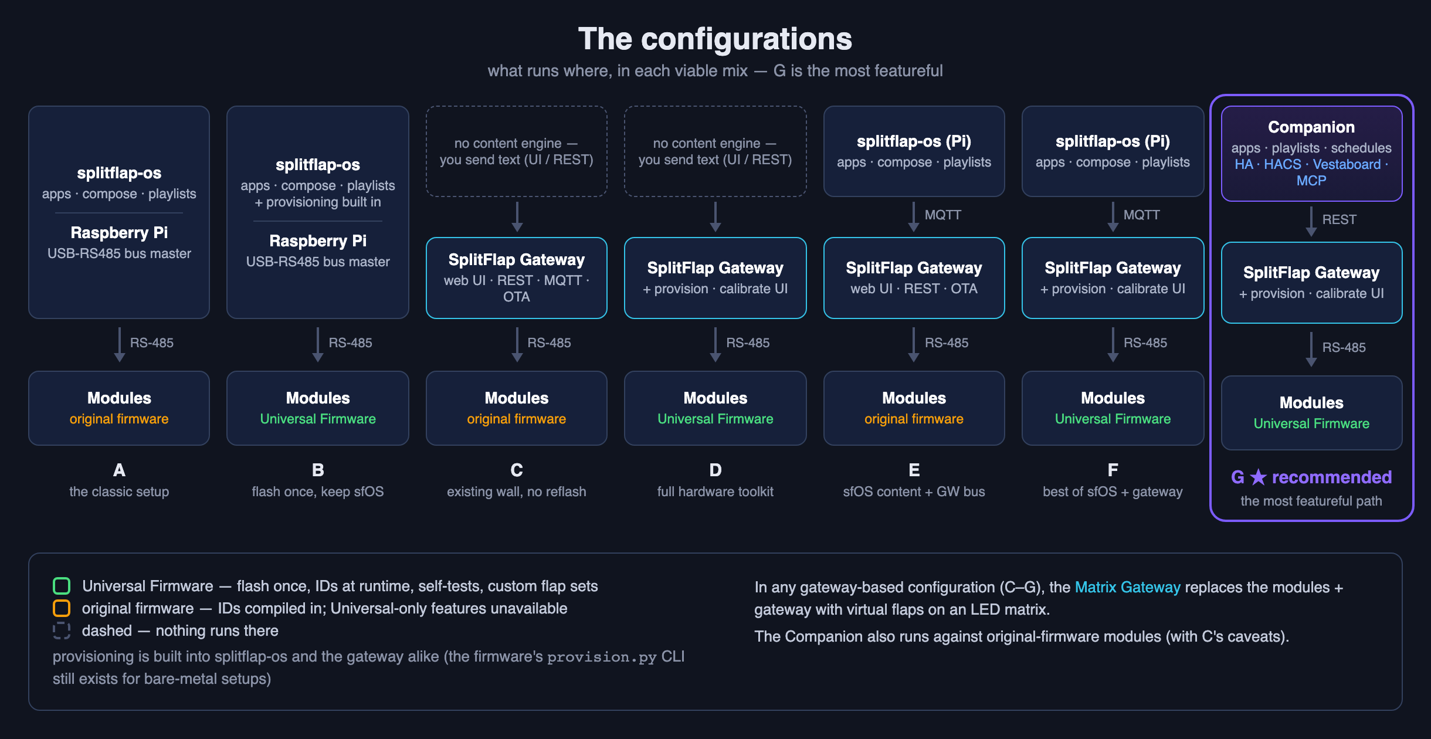
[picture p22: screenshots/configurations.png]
The seven working configurations at a glance
  
*Every combination is a working display; they differ in what you get around it*

The goal in every case was the same: make Adam's beautiful hardware easier to live with long-term — without breaking the growing community of projects already built around it.

---

## Getting Started

- **[The SplitFlap wiki](https://splitflap.iothing.net/docs/)** — the complete guide, from a bare board to a message on the wall; the [Quick Start](https://splitflap.iothing.net/docs/Quick-Start/) is the recommended path
- **[Adam G Makes on YouTube](https://www.youtube.com/@AdamGMakes)** — start here for the hardware build
- **[SplitFlapUniversalFirmware](https://github.com/avandeputte/SplitFlapUniversalFirmware)** — flash this onto your modules for runtime provisioning, custom flap sets and self-diagnostics
- **[SplitFlapGateway](https://github.com/avandeputte/SplitFlapGateway)** — flash this onto the ESP32-S3 to take the Raspberry Pi out of your display; a [prebuilt image](https://github.com/avandeputte/SplitFlapGateway/releases) needs no build environment
- **[SplitFlapGatewayCompanion](https://github.com/avandeputte/SplitFlapGatewayCompanion)** — the content engine: apps, playlists, schedules, triggers; runs in Docker or as a Home Assistant app
- **[splitflap-os](https://github.com/csader/splitflap-os)** — csader's full-featured web UI and app library, if you're keeping the Raspberry Pi
- **[Waveshare ESP32-S3-RS485-CAN on Amazon](https://www.amazon.com/dp/B0FNCWZ3D1)** — the recommended gateway hardware

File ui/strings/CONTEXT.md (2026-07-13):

# Where each string appears

Generated by `tools/i18n_context.py` -- do not edit.

Use this when translating: the same English word is often a different part of
speech in different places. In this UI **Home** is a verb (drive a reel to its zero
position), **Flap** is the physical character leaf on the reel, **Display** is both a
tab and the wall itself, and **Save**/**Revert** are buttons while **Serial Number**
and **Last Seen** are table headings.

| English | Where | What kind of thing it is |
|---|---|---|
| `' to` | — | RUNTIME MESSAGE (shown after an action, in sendChar()) |
| `(adjusting)` | — | RUNTIME MESSAGE (shown after an action, in calWizNudge()) |
| `(custom)` | — | RUNTIME MESSAGE (shown after an action, in calWizShow()) |
| `(default)` | — | RUNTIME MESSAGE (shown after an action, in calWizReset()); RUNTIME MESSAGE (shown after an action, in calWizShow()) |
| `(offset` | — | RUNTIME MESSAGE (shown after an action, in calWizHomeNudge()) |
| `(offset now` | — | RUNTIME MESSAGE (shown after an action, in calNudge()) |
| `(raw)` | — | RUNTIME MESSAGE (shown after an action, in doSend()) |
| `(using default)` | — | RUNTIME MESSAGE (shown after an action, in calOpenTune()) |
| `) and cleared custom value.` | — | RUNTIME MESSAGE (shown after an action, in calWizReset()) |
| `). Click Home Motor to verify.` | — | RUNTIME MESSAGE (shown after an action, in calSaveHo()) |
| `). Saved instantly.` | — | RUNTIME MESSAGE (shown after an action, in calNudge()) |
| `). Saved.` | — | RUNTIME MESSAGE (shown after an action, in calWizHomeNudge()) |
| `- check which module moves` | — | RUNTIME MESSAGE (shown after an action, in doHomeSN()) |
| `-- Destructive Actions` | — | RUNTIME MESSAGE (shown after an action, in openDel()) |
| `-- the reel is spinning, please wait (up to ~15s)...` | — | RUNTIME MESSAGE (shown after an action, in calCountSteps()) |
| `... watch the reel.` | — | RUNTIME MESSAGE (shown after an action, in calTuneGoto()) |
| `0 frames` | Bus Monitor tab (live RS-485 traffic) | INLINE TEXT; RUNTIME MESSAGE (shown after an action, in clearLog()) |
| `? The reel will spin a full revolution to measure its steps per revolution.` | — | RUNTIME MESSAGE (shown after an action, in calCountSteps()) |
| `? This cannot be undone.` | — | RUNTIME MESSAGE (shown after an action, in delAction()) |
| `AABBCCDD...` | Provision tab (assign bus IDs) | INPUT PLACEHOLDER (example text) |
| `AP IP` | Status tab (diagnostics) | TEXT |
| `AP fallback:` | — | (built at runtime) |
| `Absolute Target Step` | Calibration tab (tune a module's flap positions) | FORM LABEL (names the input below it -- a noun phrase) |
| `Active Flap Count` | — | (built at runtime) |
| `Adjust the value, then Test Position to move there. Lock to EEPROM when it looks right.` | Calibration tab (tune a module's flap positions) | HELP TEXT (a full sentence) |
| `Already at default (` | — | RUNTIME MESSAGE (shown after an action, in calWizReset()) |
| `Already at default -- no change needed.` | — | RUNTIME MESSAGE (shown after an action, in calWizConfirm()) |
| `Assign ID` | Provision tab (assign bus IDs) | BUTTON (an action -- use the imperative) |
| `Auckland (UTC+12/+13)` | Settings tab | DROPDOWN OPTION |
| `Auto` | Settings tab | EMPHASIS |
| `Auto (browser)` | — | RUNTIME MESSAGE (shown after an action, in go()) |
| `Auto-Home` | — | (built at runtime) |
| `Auto-scroll` | — | (built at runtime) |
| `Automatically enable Quiet Time on a daily schedule. When the window opens the gateway blanks the display and stops moving flaps for normal updates. The display is restored when the window ends. Times are in your browser's local time zone.` | Settings tab | HELP TEXT (a full sentence) |
| `Azores (UTC-1/0)` | Settings tab | DROPDOWN OPTION |
| `BLANK (home). Press Re-home, then nudge until the blank flap is centered. Nudges save instantly.` | Calibration tab (tune a module's flap positions) | TEXT |
| `Back` | Calibration tab (tune a module's flap positions) | BUTTON (an action -- use the imperative) |
| `Backup Calibration` | Settings tab | HEADING (card title -- a noun phrase) |
| `Backup created:` | — | (built at runtime) |
| `Backup file` | Settings tab | FORM LABEL (names the input below it -- a noun phrase) |
| `Bangkok (UTC+7 no DST)` | Settings tab | DROPDOWN OPTION |
| `Before you start (1 of 2)` | Calibration tab (tune a module's flap positions) | HEADING |
| `Before you start (2 of 2)` | Calibration tab (tune a module's flap positions) | HEADING |
| `Broadcasts m*v to all modules so they report their version and serial number` | Modules tab (the module grid) | TOOLTIP |
| `Broker Host / IP` | Settings tab | FORM LABEL (names the input below it -- a noun phrase) |
| `Broker OK - connected and authenticated` | — | RUNTIME MESSAGE (shown after an action, in testMqtt()) |
| `Cached EEPROM -- click Re-read for a fresh value` | — | RUNTIME MESSAGE (shown after an action, in calRefresh()) |
| `Calibrate` | Calibration tab (tune a module's flap positions) | BUTTON (an action -- use the imperative) |
| `Calibrate (Count Steps)` | Calibration tab (tune a module's flap positions) | EMPHASIS |
| `Calibrate Whole Board` | Calibration tab (tune a module's flap positions) | HEADING |
| `Calibrate Whole Board (all modules at once)` | Calibration tab (tune a module's flap positions) | BUTTON (an action -- use the imperative) |
| `Calibrated Flaps` | — | (built at runtime) |
| `Calibrating module` | — | RUNTIME MESSAGE (shown after an action, in calCountSteps()) |
| `Calibration` | Calibration tab (tune a module's flap positions) | HEADING (card title -- a noun phrase); TAB / LINK LABEL (a noun) |
| `Calibration Wizard` | Calibration tab (tune a module's flap positions) | HEADING |
| `Calibration Wizard (step through all flaps)` | Calibration tab (tune a module's flap positions) | BUTTON (an action -- use the imperative) |
| `Calibration failed.` | — | RUNTIME MESSAGE (shown after an action, in calCountSteps()) |
| `Calibration timed out (no response from module).` | — | RUNTIME MESSAGE (shown after an action, in calCountSteps()) |
| `Calibration timed out (no response).` | — | RUNTIME MESSAGE (shown after an action, in calCountSteps()) |
| `Calibration wizard complete -- all flaps reviewed.` | — | RUNTIME MESSAGE (shown after an action, in calWizFinish()) |
| `Cancel` | Calibration tab (tune a module's flap positions) | BUTTON (an action -- use the imperative) |
| `Character` | Display tab (send text/characters to the wall) | FORM LABEL (names the input below it -- a noun phrase) |
| `Character Map` | Calibration tab (tune a module's flap positions) | HEADING (card title -- a noun phrase) |
| `Character Set` | — | (built at runtime) |
| `Character Set (order = flap index, blank = leave unchanged)` | Status tab (diagnostics) | FORM LABEL (names the input below it -- a noun phrase) |
| `Choose a backup file first.` | Status tab (diagnostics) | INLINE TEXT |
| `Clear` | Bus Monitor tab (live RS-485 traffic); Settings tab | BUTTON (an action -- use the imperative) |
| `Clears the calibration flap map. The module keeps its ID but loses per-flap positions until re-calibrated.` | Modules tab (the module grid) | SMALL PRINT |
| `Clock` | Status tab (diagnostics) | HEADING |
| `Close` | Status tab (diagnostics) | BUTTON (an action -- use the imperative) |
| `Columns` | Settings tab | FORM LABEL (names the input below it -- a noun phrase) |
| `Companion` | Settings tab | EMPHASIS |
| `Companion App` | Settings tab; Status tab (diagnostics) | HEADING; HEADING (card title -- a noun phrase) |
| `Companion URL` | Settings tab | FORM LABEL (names the input below it -- a noun phrase) |
| `Confirm & Next →` | Calibration tab (tune a module's flap positions) | BUTTON (an action -- use the imperative) |
| `Confirm / adjust home position now` | Calibration tab (tune a module's flap positions) | BUTTON (an action -- use the imperative) |
| `Confirm home position` | Calibration tab (tune a module's flap positions) | HEADING |
| `Connected` | — | RUNTIME MESSAGE (shown after an action, in pollStatus()) |
| `Could not load display state` | — | RUNTIME MESSAGE (shown after an action, in refreshWall()) |
| `Could not read file.` | Status tab (diagnostics) | INLINE TEXT |
| `Count Steps` | Calibration tab (tune a module's flap positions) | BUTTON (an action -- use the imperative); RUNTIME MESSAGE (shown after an action, in calCountSteps()) |
| `Count steps on module` | — | RUNTIME MESSAGE (shown after an action, in calCountSteps()) |
| `Counting...` | — | RUNTIME MESSAGE (shown after an action, in calCountSteps()) |
| `Create Backup File` | Settings tab | BUTTON (an action -- use the imperative) |
| `Current Flap` | — | (built at runtime) |
| `Current flap set unknown -- click Refresh for a fresh read.` | Status tab (diagnostics) | HELP TEXT (a full sentence) |
| `DUP?` | Status tab (diagnostics) | INLINE TEXT |
| `Data (ASCII)` | Bus Monitor tab (live RS-485 traffic) | FORM LABEL (names the input below it -- a noun phrase) |
| `De-provision` | Provision tab (assign bus IDs) | BUTTON (an action -- use the imperative) |
| `De-provision Module` | Provision tab (assign bus IDs) | HEADING (card title -- a noun phrase) |
| `De-provisioned` | — | RUNTIME MESSAGE (shown after an action, in doDeprovision()) |
| `Debug disabled` | — | RUNTIME MESSAGE (shown after an action, in saveDebug()) |
| `Debug enabled` | — | RUNTIME MESSAGE (shown after an action, in saveDebug()) |
| `Default:` | — | RUNTIME MESSAGE (shown after an action, in calOpenTune()) |
| `Deprovision and reassign unique IDs.` | — | (built at runtime) |
| `Destructive Actions` | Modules tab (the module grid) | INLINE TEXT |
| `Dhaka (UTC+6 no DST)` | Settings tab | DROPDOWN OPTION |
| `Diagnostics` | Status tab (diagnostics) | HEADING |
| `Diagnostics -- Module` | — | RUNTIME MESSAGE (shown after an action, in runDiag()) |
| `Display` | — | TAB / LINK LABEL (a noun) |
| `Display Layout` | Settings tab | HEADING (card title -- a noun phrase) |
| `Download Log` | Bus Monitor tab (live RS-485 traffic) | BUTTON (an action -- use the imperative) |
| `Dubai (UTC+4 no DST)` | Settings tab | DROPDOWN OPTION |
| `EEPROM` | Status tab (diagnostics) | TEXT |
| `EEPROM is cached -- click Refresh for a fresh read` | — | RUNTIME MESSAGE (shown after an action, in done()) |
| `EEPROM read fresh from module` | — | RUNTIME MESSAGE (shown after an action, in calRefresh()) |
| `Enable Home Assistant integration` | — | (built at runtime) |
| `Enable Serial Debug Output` | — | (built at runtime) |
| `Enable schedule` | — | (built at runtime) |
| `Enable verbose serial output on the native USB serial port (115200 baud). Shows every RX/TX frame, MQTT events, and module activity.` | Settings tab | HELP TEXT (a full sentence) |
| `Enter a character` | — | RUNTIME MESSAGE (shown after an action, in sendChar()) |
| `Enter a flap count or character set.` | — | RUNTIME MESSAGE (shown after an action, in saveFlapConfig()) |
| `Enter a flap number 1-` | — | RUNTIME MESSAGE (shown after an action, in bmJump()) |
| `Enter a valid home offset.` | — | RUNTIME MESSAGE (shown after an action, in calSaveHo()) |
| `Enter a valid step.` | — | RUNTIME MESSAGE (shown after an action, in calTuneGoto()); RUNTIME MESSAGE (shown after an action, in calTuneLock()) |
| `Enter a valid total steps.` | — | RUNTIME MESSAGE (shown after an action, in calSaveTs()) |
| `Enter an ID from 0 to 254.` | — | RUNTIME MESSAGE (shown after an action, in calSelectAny()) |
| `Erase EEPROM` | — | (built at runtime) |
| `Error` | — | RUNTIME MESSAGE (shown after an action, in g()) |
| `Error loading layout` | Status tab (diagnostics) | INLINE TEXT |
| `Error loading layout.` | — | RUNTIME MESSAGE (shown after an action, in bmStart()) |
| `Error reading module` | — | RUNTIME MESSAGE (shown after an action, in bmCell()) |
| `Error:` | — | RUNTIME MESSAGE (shown after an action); RUNTIME MESSAGE (shown after an action, in bmCell()); RUNTIME MESSAGE (shown after an action, in calCountSteps()); RUNTIME MESSAGE (shown after an action, in calHomeMotor()); RUNTIME MESSAGE (shown after an action, in calNudge()); RUNTIME MESSAGE (shown after an action, in calRefresh()); RUNTIME MESSAGE (shown after an action, in calRevertHo()); RUNTIME MESSAGE (shown after an action, in calRevertTs()); RUNTIME MESSAGE (shown after an action, in calSaveHo()); RUNTIME MESSAGE (shown after an action, in calSaveTs()); RUNTIME MESSAGE (shown after an action, in calTuneGoto()); RUNTIME MESSAGE (shown after an action, in calTuneLock()); RUNTIME MESSAGE (shown after an action, in calTuneRevert()); RUNTIME MESSAGE (shown after an action, in calWizHomeNudge()); RUNTIME MESSAGE (shown after an action, in delAction()); RUNTIME MESSAGE (shown after an action, in doDeprovision()); RUNTIME MESSAGE (shown after an action, in doHomeSN()); RUNTIME MESSAGE (shown after an action, in doProvision()); RUNTIME MESSAGE (shown after an action, in doSend()); RUNTIME MESSAGE (shown after an action, in g()); RUNTIME MESSAGE (shown after an action, in homeAll()); RUNTIME MESSAGE (shown after an action, in refreshModules()); RUNTIME MESSAGE (shown after an action, in saveDebug()); RUNTIME MESSAGE (shown after an action, in saveFlapConfig()); RUNTIME MESSAGE (shown after an action, in saveGrid()); RUNTIME MESSAGE (shown after an action, in saveHa()); RUNTIME MESSAGE (shown after an action, in saveMqtt()); RUNTIME MESSAGE (shown after an action, in saveOTA()); RUNTIME MESSAGE (shown after an action, in saveTz()); RUNTIME MESSAGE (shown after an action, in saveWifi()); RUNTIME MESSAGE (shown after an action, in sendChar()); RUNTIME MESSAGE (shown after an action, in sendIndex()); RUNTIME MESSAGE (shown after an action, in sendText()); RUNTIME MESSAGE (shown after an action, in testMqtt()) |
| `Every module should be showing this flap:` | Calibration tab (tune a module's flap positions) | TEXT |
| `Exit` | Calibration tab (tune a module's flap positions) | BUTTON (an action -- use the imperative) |
| `Expected: -` | Calibration tab (tune a module's flap positions) | TEXT |
| `FW:` | — | (built at runtime) |
| `FW: v7 or earlier` | Status tab (diagnostics) | INLINE TEXT |
| `Factory Reset` | — | (built at runtime) |
| `Failed:` | — | RUNTIME MESSAGE (shown after an action, in testMqtt()) |
| `Finish` | Calibration tab (tune a module's flap positions) | BUTTON (an action -- use the imperative) |
| `Firmware` | — | (built at runtime) |
| `Flap` | — | RUNTIME MESSAGE (shown after an action, in bmShow()); RUNTIME MESSAGE (shown after an action, in calWizShow()) |
| `Flap Count (1-64, blank = leave unchanged)` | Status tab (diagnostics) | FORM LABEL (names the input below it -- a noun phrase) |
| `Flap Index (0-63)` | Display tab (send text/characters to the wall) | FORM LABEL (names the input below it -- a noun phrase) |
| `Flap Set` | Status tab (diagnostics) | TEXT |
| `Flap count must be 1-64.` | — | RUNTIME MESSAGE (shown after an action, in saveFlapConfig()) |
| `Frames RX` | Status tab (diagnostics) | TEXT |
| `Frames TX` | Status tab (diagnostics) | TEXT |
| `Free Heap` | Status tab (diagnostics) | TEXT |
| `From` | — | (built at runtime) |
| `Gateway Time` | Status tab (diagnostics) | TEXT |
| `Go` | Calibration tab (tune a module's flap positions) | BUTTON (an action -- use the imperative) |
| `Green = custom EEPROM value. Grey = firmware default. Click a character to tune its position, or run the wizard to step through every flap.` | Calibration tab (tune a module's flap positions) | HELP TEXT (a full sentence) |
| `HELLO WORLD` | Display tab (send text/characters to the wall) | INPUT PLACEHOLDER (example text) |
| `Hall sensor self-test (T)` | Status tab (diagnostics) | H4 |
| `Has the` | — | (built at runtime) |
| `Have you run` | — | (built at runtime) |
| `Helsinki/Athens (UTC+2/+3)` | Settings tab | DROPDOWN OPTION |
| `Home` | Status tab (diagnostics) | BUTTON (an action -- use the imperative) |
| `Home All` | Calibration tab (tune a module's flap positions); Display tab (send text/characters to the wall) | BUTTON (an action -- use the imperative) |
| `Home Assistant` | Settings tab | HEADING (card title -- a noun phrase) |
| `Home Assistant integration disabled` | — | RUNTIME MESSAGE (shown after an action, in saveHa()) |
| `Home Assistant integration enabled` | — | RUNTIME MESSAGE (shown after an action, in saveHa()) |
| `Home Motor` | Calibration tab (tune a module's flap positions) | BUTTON (an action -- use the imperative) |
| `Home Offset` | — | (built at runtime) |
| `Home error:` | — | RUNTIME MESSAGE (shown after an action, in calWizHomeRehome()); RUNTIME MESSAGE (shown after an action, in calWizHomeStage()) |
| `Home is centered -- start wizard` | Calibration tab (tune a module's flap positions) | BUTTON (an action -- use the imperative) |
| `Home offset reset to default (` | — | RUNTIME MESSAGE (shown after an action, in calRevertHo()) |
| `Home offset saved (` | — | RUNTIME MESSAGE (shown after an action, in calSaveHo()) |
| `Home this module to identify it` | — | (built at runtime) |
| `Homed. Is the blank flap centered?` | — | RUNTIME MESSAGE (shown after an action, in calWizHomeStage()) |
| `Homes every module (broadcasts m*h) so all reels return to their home flap` | Calibration tab (tune a module's flap positions); Display tab (send text/characters to the wall) | TOOLTIP |
| `Homing SN:` | — | RUNTIME MESSAGE (shown after an action, in doHomeSN()) |
| `Homing all modules – reels returning home` | — | (built at runtime) |
| `Homing all modules…` | — | (built at runtime) |
| `Homing module` | — | RUNTIME MESSAGE (shown after an action, in calHomeMotor()) |
| `Homing...` | — | RUNTIME MESSAGE (shown after an action, in calWizHomeStage()) |
| `Hostname of the time server used to sync the clock. Default: pool.ntp.org` | Settings tab | HELP TEXT (a full sentence) |
| `How the modules are physically arranged, for the Live Display on the Display tab. Modules map left-to-right, top-to-bottom by ID (module 0 = top-left).` | Settings tab | HELP TEXT (a full sentence) |
| `ID:` | — | (built at runtime) |
| `Identify All` | Modules tab (the module grid) | BUTTON (an action -- use the imperative) |
| `Identifying...` | — | RUNTIME MESSAGE (shown after an action, in refreshModules()) |
| `Invalid JSON file.` | Status tab (diagnostics) | INLINE TEXT |
| `Jump to flap:` | Calibration tab (tune a module's flap positions) | INLINE TEXT |
| `KB` | — | RUNTIME MESSAGE (shown after an action, in pollStatus()) |
| `Karachi (UTC+5 no DST)` | Settings tab | DROPDOWN OPTION |
| `Known Modules` | Modules tab (the module grid) | HEADING (card title -- a noun phrase) |
| `LEGACY` | Status tab (diagnostics) | INLINE TEXT |
| `Language` | Settings tab | FORM LABEL (names the input below it -- a noun phrase); HEADING (card title -- a noun phrase) |
| `Language of this dashboard.` | — | (built at runtime) |
| `Last Char` | — | (built at runtime) |
| `Last Seen` | — | (built at runtime) |
| `Last flap reached -- click Finish.` | — | RUNTIME MESSAGE (shown after an action, in bmNext()) |
| `Layout saved` | — | RUNTIME MESSAGE (shown after an action, in saveGrid()) |
| `Leave blank for no password` | Settings tab | INPUT PLACEHOLDER (example text) |
| `Leave blank for open network` | Settings tab | INPUT PLACEHOLDER (example text) |
| `List cleared, identifying all modules -- refreshing in 2s` | — | RUNTIME MESSAGE (shown after an action, in refreshModules()) |
| `Live Display` | Display tab (send text/characters to the wall) | HEADING (card title -- a noun phrase) |
| `Loading board layout...` | — | RUNTIME MESSAGE (shown after an action, in bmStart()) |
| `Loading layout...` | — | RUNTIME MESSAGE (shown after an action, in calLoadModules()) |
| `Loading module list...` | — | RUNTIME MESSAGE (shown after an action, in doBackup()) |
| `Loading modules...` | Calibration tab (tune a module's flap positions) | TEXT |
| `Loading...` | Calibration tab (tune a module's flap positions); Display tab (send text/characters to the wall); Modules tab (the module grid); Provision tab (assign bus IDs) | TEXT |
| `Lock to EEPROM` | Calibration tab (tune a module's flap positions) | BUTTON (an action -- use the imperative) |
| `Locked to EEPROM at step` | — | RUNTIME MESSAGE (shown after an action, in calTuneLock()) |
| `London (UTC+0/+1)` | Settings tab | DROPDOWN OPTION |
| `Look at the module. If it is centered, confirm. If not, nudge until it is.` | Calibration tab (tune a module's flap positions) | TEXT |
| `Look at the wall. Click any module showing the wrong flap to nudge it (same controls as the single-module tuner), then advance to the next flap.` | Calibration tab (tune a module's flap positions) | TEXT |
| `Lowest minimum-ever free stack across tasks. Trending toward 0 warns of a stack overflow before it crashes.` | Status tab (diagnostics) | TOOLTIP |
| `MAINTENANCE MODE - external MQTT commands are being ignored` | — | (built at runtime) |
| `MQTT` | Settings tab; Status tab (diagnostics) | HEADING (card title -- a noun phrase); TEXT |
| `MQTT saved - reconnecting...` | — | RUNTIME MESSAGE (shown after an action, in saveMqtt()) |
| `Maintenance mode is strongly recommended before calibrating, so external commands received via MQTT cannot move the reels mid-calibration.` | Calibration tab (tune a module's flap positions) | INLINE TEXT |
| `Matches default -- cleared custom value.` | — | RUNTIME MESSAGE (shown after an action, in calWizConfirm()) |
| `Measured` | — | RUNTIME MESSAGE (shown after an action, in calCountSteps()) |
| `Mechanical self-test (M)` | Status tab (diagnostics) | H4 |
| `Min Heap Ever` | Status tab (diagnostics) | TEXT |
| `Module` | Calibration tab (tune a module's flap positions) | HEADING (card title -- a noun phrase); RUNTIME MESSAGE (shown after an action, in bmCell()); RUNTIME MESSAGE (shown after an action, in calSelect()) |
| `Module #` | — | RUNTIME MESSAGE (shown after an action, in openDel()); RUNTIME MESSAGE (shown after an action, in openInfo()) |
| `Module EEPROM` | Modules tab (the module grid) | INLINE TEXT |
| `Module ID` | Display tab (send text/characters to the wall) | FORM LABEL (names the input below it -- a noun phrase) |
| `Module ID (-1 = all modules)` | Provision tab (assign bus IDs) | FORM LABEL (names the input below it -- a noun phrase) |
| `Module ID (-1 = all)` | Display tab (send text/characters to the wall) | FORM LABEL (names the input below it -- a noun phrase) |
| `Modules` | Status tab (diagnostics) | TAB / LINK LABEL (a noun); TEXT |
| `Modules without an ID broadcast their serial number every 10-15 seconds. Use Home to identify which physical module it is, then assign an ID.` | Provision tab (assign bus IDs) | HELP TEXT (a full sentence) |
| `Monitor` | Bus Monitor tab (live RS-485 traffic) | HEADING (card title -- a noun phrase); TAB / LINK LABEL (a noun) |
| `Moscow (UTC+3 no DST)` | Settings tab | DROPDOWN OPTION |
| `Motor spinning` | — | (built at runtime) |
| `Move error:` | — | RUNTIME MESSAGE (shown after an action, in bmShow()); RUNTIME MESSAGE (shown after an action, in calWizNudge()); RUNTIME MESSAGE (shown after an action, in calWizShow()) |
| `Moving to step` | — | RUNTIME MESSAGE (shown after an action, in calTuneGoto()) |
| `NTP Server` | Settings tab | FORM LABEL (names the input below it -- a noun phrase) |
| `NTP Sync` | Status tab (diagnostics) | TEXT |
| `Network` | Status tab (diagnostics) | HEADING |
| `Network name` | Settings tab | INPUT PLACEHOLDER (example text) |
| `New ID (0-254)` | Provision tab (assign bus IDs) | FORM LABEL (names the input below it -- a noun phrase) |
| `New module? Running Calibrate is recommended to confirm this reel's actual step count and home offset. It spins one full revolution to measure steps/rev, then saves the result.` | Calibration tab (tune a module's flap positions) | INLINE TEXT |
| `Next →` | Calibration tab (tune a module's flap positions) | BUTTON (an action -- use the imperative) |
| `No -- run Calibrate now` | Calibration tab (tune a module's flap positions) | BUTTON (an action -- use the imperative) |
| `No calibration data could be read.` | Status tab (diagnostics) | INLINE TEXT |
| `No layout.` | — | RUNTIME MESSAGE (shown after an action, in bmRenderGrid()) |
| `No modules detected yet.` | Status tab (diagnostics) | HELP TEXT (a full sentence) |
| `No modules found in backup file.` | Status tab (diagnostics) | INLINE TEXT |
| `No modules with serial numbers found. Run Identify All first.` | Status tab (diagnostics) | INLINE TEXT |
| `No response from module` | — | RUNTIME MESSAGE (shown after an action, in bmCell()) |
| `No response from module -- click Re-read to try again.` | — | RUNTIME MESSAGE (shown after an action, in calRefresh()) |
| `No response to the stats query -- the module did not answer (check it is powered and on the bus).` | Status tab (diagnostics) | HELP TEXT (a full sentence) |
| `No unprovisioned modules seen yet.` | Status tab (diagnostics) | HELP TEXT (a full sentence) |
| `Nothing to send.` | — | RUNTIME MESSAGE (shown after an action, in doSend()) |
| `Nudge moves the reel and saves the offset instantly. Press Home to verify.` | Calibration tab (tune a module's flap positions) | HELP TEXT (a full sentence) |
| `Nudged` | — | RUNTIME MESSAGE (shown after an action, in calNudge()); RUNTIME MESSAGE (shown after an action, in calWizHomeNudge()) |
| `OTA Firmware Update` | Settings tab | HEADING (card title -- a noun phrase) |
| `OTA Password` | Settings tab | FORM LABEL (names the input below it -- a noun phrase) |
| `OTA password saved` | — | RUNTIME MESSAGE (shown after an action, in saveOTA()) |
| `Off` | — | RUNTIME MESSAGE (shown after an action, in pollStatus()) |
| `Open Firmware Updater →` | Settings tab | TAB / LINK LABEL (a noun) |
| `Or pick one module to calibrate individually:` | Calibration tab (tune a module's flap positions) | HELP TEXT (a full sentence) |
| `Paris/Berlin (UTC+1/+2)` | Settings tab | DROPDOWN OPTION |
| `Password` | Settings tab | FORM LABEL (names the input below it -- a noun phrase) |
| `Pause` | — | (built at runtime) |
| `Pending` | — | RUNTIME MESSAGE (shown after an action, in pollStatus()) |
| `Port` | Settings tab | FORM LABEL (names the input below it -- a noun phrase) |
| `Possible Duplicate ID` | Status tab (diagnostics) | INLINE TEXT |
| `Preserve current module IDs` | — | (built at runtime) |
| `Prev` | Calibration tab (tune a module's flap positions) | BUTTON (an action -- use the imperative) |
| `Protects ArduinoOTA (IDE/command-line) uploads. The web updater above is always accessible.` | Settings tab | HELP TEXT (a full sentence) |
| `Provision` | — | TAB / LINK LABEL (a noun) |
| `Provision: Assign ID by Serial Number` | Provision tab (assign bus IDs) | HEADING (card title -- a noun phrase) |
| `Provisioned` | — | (built at runtime) |
| `Provisioning sent` | — | RUNTIME MESSAGE (shown after an action, in doProvision()) |
| `Pub: .../rx   .../tx   .../status   .../flap/adv   .../flap/ack` | — | (built at runtime) |
| `QUIET TIME - the display is blanked and flaps will not move. It is restored when Quiet Time ends (calibration still works)` | — | TEXT |
| `Queued -- runs after the Hall test.` | Status tab (diagnostics) | HELP TEXT (a full sentence) |
| `Quiet Time Schedule` | Settings tab | HEADING (card title -- a noun phrase) |
| `RS-485 Bus` | Status tab (diagnostics) | HEADING |
| `Raw — send verbatim, skip sanitizing & framing (debug)` | — | (built at runtime) |
| `Re-home (verify)` | Calibration tab (tune a module's flap positions) | BUTTON (an action -- use the imperative) |
| `Re-homed. Check the blank flap is centered.` | — | RUNTIME MESSAGE (shown after an action, in calWizHomeRehome()) |
| `Re-homing...` | — | RUNTIME MESSAGE (shown after an action, in calWizHomeRehome()) |
| `Re-read EEPROM` | Calibration tab (tune a module's flap positions) | BUTTON (an action -- use the imperative) |
| `Reading EEPROM from module` | — | RUNTIME MESSAGE (shown after an action, in calRefresh()) |
| `Reading module` | — | RUNTIME MESSAGE (shown after an action, in bmCell()); RUNTIME MESSAGE (shown after an action, in next()) |
| `Reading module #` | — | (built at runtime) |
| `Reading stats snapshot...` | Status tab (diagnostics) | HELP TEXT (a full sentence) |
| `Reads the EEPROM calibration from every known module (by serial number) and saves it to a JSON file you can download. Make sure all modules have been identified first (see the Modules tab).` | Settings tab | HELP TEXT (a full sentence) |
| `Refresh` | Calibration tab (tune a module's flap positions); Modules tab (the module grid) | BUTTON (an action -- use the imperative) |
| `Request failed` | — | RUNTIME MESSAGE (shown after an action, in homeAll()) |
| `Reset error:` | — | RUNTIME MESSAGE (shown after an action, in calWizReset()) |
| `Reset to Default` | Calibration tab (tune a module's flap positions) | BUTTON (an action -- use the imperative) |
| `Reset to default (` | — | RUNTIME MESSAGE (shown after an action, in calWizReset()) |
| `Reset to default 2832` | Calibration tab (tune a module's flap positions) | TOOLTIP |
| `Reset to default 4096` | Calibration tab (tune a module's flap positions) | TOOLTIP |
| `Restore Calibration` | Settings tab | HEADING (card title -- a noun phrase) |
| `Restore complete:` | — | (built at runtime) |
| `Restore from File` | Settings tab | BUTTON (an action -- use the imperative) |
| `Restores all module settings to firmware defaults (home offset, total steps, flap map).` | Modules tab (the module grid) | SMALL PRINT |
| `Restoring module` | — | RUNTIME MESSAGE (shown after an action, in next()) |
| `Revert` | Calibration tab (tune a module's flap positions) | BUTTON (an action -- use the imperative) |
| `Revert to Default` | Calibration tab (tune a module's flap positions) | BUTTON (an action -- use the imperative) |
| `Rotations` | — | (built at runtime) |
| `Rows` | Settings tab | FORM LABEL (names the input below it -- a noun phrase) |
| `Run again` | Status tab (diagnostics) | BUTTON (an action -- use the imperative) |
| `Run the calibrate command: the reel spins one full revolution to measure its steps per revolution` | Calibration tab (tune a module's flap positions) | TOOLTIP |
| `SN:` | — | (built at runtime) |
| `SSID` | Settings tab | FORM LABEL (names the input below it -- a noun phrase) |
| `Sao Paulo (UTC-3/-2)` | Settings tab | DROPDOWN OPTION |
| `Save` | Calibration tab (tune a module's flap positions); Settings tab | BUTTON (an action -- use the imperative) |
| `Save Flap Config` | Status tab (diagnostics) | BUTTON (an action -- use the imperative) |
| `Save Layout` | Settings tab | BUTTON (an action -- use the imperative) |
| `Save MQTT` | Settings tab | BUTTON (an action -- use the imperative) |
| `Save OTA Password` | Settings tab | BUTTON (an action -- use the imperative) |
| `Save Schedule` | Settings tab | BUTTON (an action -- use the imperative) |
| `Save Time Settings` | Settings tab | BUTTON (an action -- use the imperative) |
| `Save WiFi` | Settings tab | BUTTON (an action -- use the imperative) |
| `Save error:` | — | RUNTIME MESSAGE (shown after an action, in calWizConfirm()) |
| `Saved` | — | RUNTIME MESSAGE (shown after an action, in g()) |
| `Saved - times are` | — | RUNTIME MESSAGE (shown after an action, in g()) |
| `Saved custom position` | — | RUNTIME MESSAGE (shown after an action, in calWizConfirm()) |
| `Saved. Refreshing...` | — | RUNTIME MESSAGE (shown after an action, in saveFlapConfig()) |
| `Saving...` | — | RUNTIME MESSAGE (shown after an action, in saveFlapConfig()) |
| `Self-Reported ID` | — | (built at runtime) |
| `Send` | Bus Monitor tab (live RS-485 traffic) | BUTTON (an action -- use the imperative) |
| `Send Character` | Display tab (send text/characters to the wall) | BUTTON (an action -- use the imperative) |
| `Send Frame` | Bus Monitor tab (live RS-485 traffic) | HEADING (card title -- a noun phrase) |
| `Send Index` | Display tab (send text/characters to the wall) | BUTTON (an action -- use the imperative) |
| `Send Single Character` | Display tab (send text/characters to the wall) | HEADING (card title -- a noun phrase) |
| `Send Text to Display` | Display tab (send text/characters to the wall) | HEADING (card title -- a noun phrase) |
| `Send by Index` | Display tab (send text/characters to the wall) | HEADING (card title -- a noun phrase) |
| `Send to Display` | Display tab (send text/characters to the wall) | BUTTON (an action -- use the imperative) |
| `Sends Reset (R): the module forgets its assigned ID and returns to advertising for re-provisioning.` | Modules tab (the module grid) | SMALL PRINT |
| `Sends the Reset (R) command which erases the stored ID and returns the module to unprovisioned state.` | Provision tab (assign bus IDs) | HELP TEXT (a full sentence) |
| `Sent` | — | RUNTIME MESSAGE (shown after an action, in doSend()); RUNTIME MESSAGE (shown after an action, in sendIndex()); RUNTIME MESSAGE (shown after an action, in sendText()) |
| `Sent '` | — | RUNTIME MESSAGE (shown after an action, in sendChar()) |
| `Serial Debug` | Settings tab | HEADING (card title -- a noun phrase) |
| `Serial Number` | Provision tab (assign bus IDs) | FORM LABEL (names the input below it -- a noun phrase) |
| `Set by the ?lang= in the URL.` | — | RUNTIME MESSAGE (shown after an action, in go()) |
| `Settings` | — | TAB / LINK LABEL (a noun) |
| `Shanghai/HK/Singapore (UTC+8)` | Settings tab | DROPDOWN OPTION |
| `Showing:` | — | (built at runtime) |
| `Skip` | Calibration tab (tune a module's flap positions) | BUTTON (an action -- use the imperative) |
| `Spinning the reel to check the home sensor (~10-20s)...` | Status tab (diagnostics) | HELP TEXT (a full sentence) |
| `Split-Flap Gateway` | — | TITLE |
| `Split-Flap-GW` | Settings tab | STRONG |
| `Stack Min (task)` | Status tab (diagnostics) | TEXT |
| `Start Module ID` | Display tab (send text/characters to the wall) | FORM LABEL (names the input below it -- a noun phrase) |
| `Stats snapshot (Q)` | Status tab (diagnostics) | H4 |
| `Status` | — | TAB / LINK LABEL (a noun) |
| `Steps / Rev` | — | (built at runtime) |
| `Stops fetching new frames. Frames beyond the 64-entry ring are lost while paused.` | Bus Monitor tab (live RS-485 traffic) | TOOLTIP |
| `Sub: .../flap/set   .../flap/home   .../flap/provision   .../send` | — | (built at runtime) |
| `Sydney (UTC+10/+11)` | Settings tab | DROPDOWN OPTION |
| `Synced` | — | RUNTIME MESSAGE (shown after an action, in pollStatus()) |
| `System Health` | Status tab (diagnostics) | HEADING |
| `Test Connection` | Settings tab | BUTTON (an action -- use the imperative) |
| `Test Position (GOTO)` | Calibration tab (tune a module's flap positions) | BUTTON (an action -- use the imperative) |
| `Testing...` | — | RUNTIME MESSAGE (shown after an action, in testMqtt()) |
| `Text` | Display tab (send text/characters to the wall) | FORM LABEL (names the input below it -- a noun phrase) |
| `The SplitFlap Gateway Companion registers itself here automatically. When a URL is set, a` | — | (built at runtime) |
| `The wizard relies on the measured step count to place each flap. If it is wrong, every flap will be off. Calibrate first if you haven't.` | Calibration tab (tune a module's flap positions) | HELP TEXT (a full sentence) |
| `These actions cannot be undone. You will be asked to confirm.` | Modules tab (the module grid) | HELP TEXT (a full sentence) |
| `This flap should be showing on the reel (homed):` | Calibration tab (tune a module's flap positions) | TEXT |
| `This flap should be showing on the reel:` | Calibration tab (tune a module's flap positions) | TEXT |
| `This is the home offset. If the blank flap is off-center, every character will be too. Confirm it now if you haven't.` | Calibration tab (tune a module's flap positions) | HELP TEXT (a full sentence) |
| `Time settings saved` | — | RUNTIME MESSAGE (shown after an action, in saveTz()) |
| `Timezone` | Settings tab | FORM LABEL (names the input below it -- a noun phrase); HEADING (card title -- a noun phrase) |
| `To` | — | (built at runtime) |
| `Tokyo (UTC+9 no DST)` | Settings tab | DROPDOWN OPTION |
| `Topic Prefix` | Settings tab | FORM LABEL (names the input below it -- a noun phrase) |
| `Total steps measured and saved:` | — | RUNTIME MESSAGE (shown after an action, in calCountSteps()) |
| `Total steps reset to default (` | — | RUNTIME MESSAGE (shown after an action, in calRevertTs()) |
| `Total steps saved (` | — | RUNTIME MESSAGE (shown after an action, in calSaveTs()) |
| `Tune` | Calibration tab (tune a module's flap positions) | HEADING |
| `Tune:` | — | RUNTIME MESSAGE (shown after an action, in calOpenTune()) |
| `Turn Off Maintenance` | — | BUTTON (an action -- use the imperative) |
| `Turn On Maintenance` | Calibration tab (tune a module's flap positions) | BUTTON (an action -- use the imperative) |
| `Two ways to calibrate, both using the same nudge controls and writing to each module's EEPROM: sweep the` | — | (built at runtime) |
| `US Central (UTC-6/-5)` | Settings tab | DROPDOWN OPTION |
| `US Eastern (UTC-5/-4)` | Settings tab | DROPDOWN OPTION |
| `US Mountain (UTC-7/-6)` | Settings tab | DROPDOWN OPTION |
| `US Mountain AZ (UTC-7 no DST)` | Settings tab | DROPDOWN OPTION |
| `US Pacific (UTC-8/-7)` | Settings tab | DROPDOWN OPTION |
| `UTC` | Settings tab | DROPDOWN OPTION |
| `Unprovisioned` | Status tab (diagnostics) | INLINE TEXT |
| `Unprovisioned Modules` | Provision tab (assign bus IDs) | HEADING (card title -- a noun phrase) |
| `Unset in EEPROM -- now uses default (` | — | RUNTIME MESSAGE (shown after an action, in calTuneRevert()) |
| `Upload a backup file to restore calibration to each module by serial number. Modules are matched by serial number, so IDs can differ from when the backup was made.` | Settings tab | HELP TEXT (a full sentence) |
| `Upload new firmware directly from your browser — no USB cable or Arduino IDE required.` | Settings tab | HELP TEXT (a full sentence) |
| `Uptime` | Status tab (diagnostics) | TEXT |
| `Used for bus monitor timestamps. Takes effect immediately after saving.` | Settings tab | HELP TEXT (a full sentence) |
| `Username` | Settings tab | FORM LABEL (names the input below it -- a noun phrase) |
| `WiFi` | Settings tab | HEADING (card title -- a noun phrase) |
| `WiFi IP` | Status tab (diagnostics) | TEXT |
| `WiFi saved - reconnecting...` | — | RUNTIME MESSAGE (shown after an action, in saveWifi()) |
| `Windows-1252: ASCII plus € and accented letters (é à ü ñ ç …). Each glyph is one flap.` | Status tab (diagnostics) | TEXT |
| `Yes -- home is confirmed, start wizard` | Calibration tab (tune a module's flap positions) | BUTTON (an action -- use the imperative) |
| `Yes -- step count is confirmed` | Calibration tab (tune a module's flap positions) | BUTTON (an action -- use the imperative) |
| `all modules` | — | RUNTIME MESSAGE (shown after an action, in doDeprovision()); RUNTIME MESSAGE (shown after an action, in sendChar()) |
| `been confirmed? When homed, the blank (black) flap should sit centered in the window.` | — | (built at runtime) |
| `below to adjust it on its own.` | — | (built at runtime) |
| `but save failed:` | — | RUNTIME MESSAGE (shown after an action, in calCountSteps()) |
| `cell(s) shown` | — | RUNTIME MESSAGE (shown after an action, in buildWall()) |
| `could not start calibration` | — | RUNTIME MESSAGE (shown after an action, in calCountSteps()) |
| `flap-by-flap (fast for a full wall -- every module shows the same flap at once and you nudge only the ones that look wrong), or pick a` | — | (built at runtime) |
| `follows your browser, the same way the light/dark theme does. This is stored in your browser, not on the gateway, so it is per-device.` | — | (built at runtime) |
| `grid -` | — | RUNTIME MESSAGE (shown after an action, in buildWall()) |
| `healthy  ·` | — | (built at runtime) |
| `home position` | Calibration tab (tune a module's flap positions) | EMPHASIS |
| `in progress...` | — | RUNTIME MESSAGE (shown after an action, in delAction()) |
| `link appears in the header.` | — | (built at runtime) |
| `looks like a DUPLICATE ID -- nudging may move or save the wrong module. Continue?` | — | RUNTIME MESSAGE (shown after an action, in bmCell()) |
| `module #` | — | RUNTIME MESSAGE (shown after an action, in sendChar()) |
| `more rotations catch intermittent faults but take longer (5-20)` | — | (built at runtime) |
| `n/a (legacy)` | Status tab (diagnostics) | INLINE TEXT |
| `needs attention  ·` | — | (built at runtime) |
| `no response` | — | RUNTIME MESSAGE (shown after an action, in bmCell()) |
| `no response from module` | — | RUNTIME MESSAGE (shown after an action, in calRefresh()) |
| `not connected` | — | RUNTIME MESSAGE (shown after an action, in pollStatus()) |
| `offset -` | Calibration tab (tune a module's flap positions) | TEXT |
| `on module #` | — | RUNTIME MESSAGE (shown after an action, in delAction()) |
| `on this module to confirm the reel's actual step count?` | — | (built at runtime) |
| `or tune any ID:` | Calibration tab (tune a module's flap positions) | INLINE TEXT |
| `pool.ntp.org` | Settings tab | INPUT PLACEHOLDER (example text) |
| `s ago)` | — | RUNTIME MESSAGE (shown after an action, in pollStatus()) |
| `sent.` | — | RUNTIME MESSAGE (shown after an action, in delAction()) |
| `single module` | Calibration tab (tune a module's flap positions) | EMPHASIS |
| `step -` | Calibration tab (tune a module's flap positions) | TEXT |
| `steps/rev. Saving to module...` | — | RUNTIME MESSAGE (shown after an action, in calCountSteps()) |
| `uncheck to also reassign IDs from the backup)` | Settings tab | INLINE TEXT |
| `watch  ·` | — | (built at runtime) |
| `whole board` | Calibration tab (tune a module's flap positions) | EMPHASIS |
| `\|  Current EEPROM:` | — | RUNTIME MESSAGE (shown after an action, in calOpenTune()) |

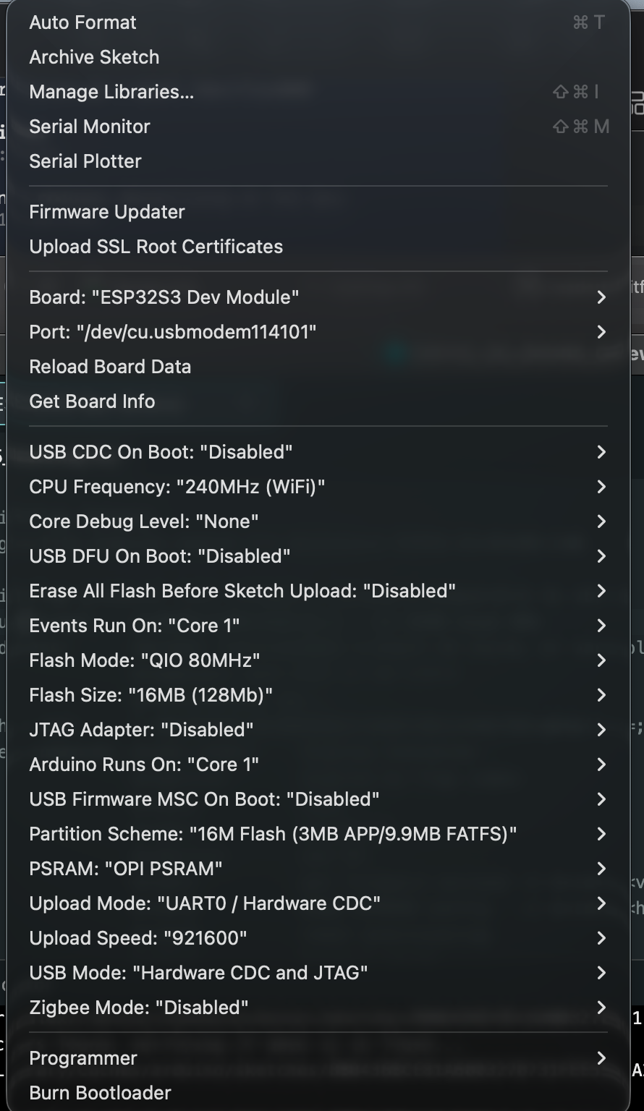
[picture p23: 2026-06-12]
screenshots/ArduinoIDESettings.png

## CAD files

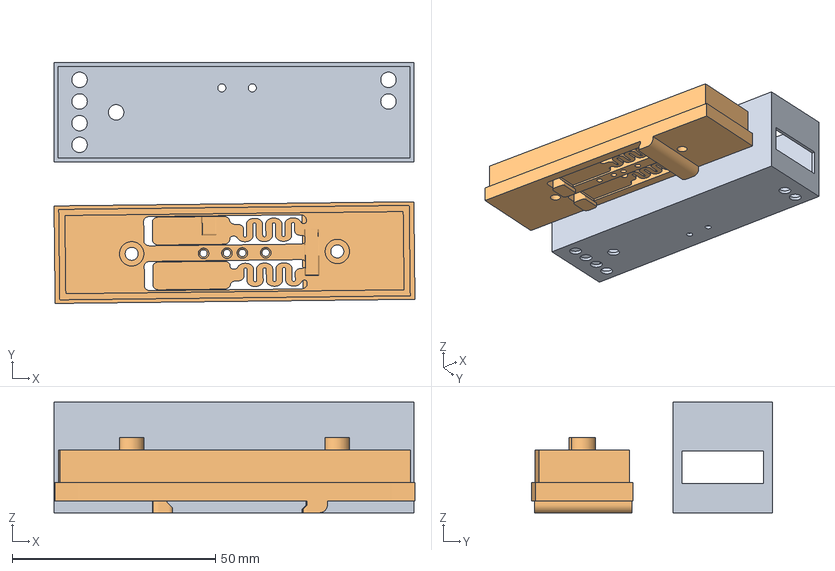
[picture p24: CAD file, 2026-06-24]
SplitFlapGatewayCase.3mf
88.8 x 59.3 x 27.2 mm
esp2.stl
DIN Rail Mount

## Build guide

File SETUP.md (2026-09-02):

# Build & Flash Guide — VS Code + PlatformIO

This guide walks you through everything needed to build the Split-Flap **Gateway**
firmware and load it onto the board, starting from a clean computer:

1. [Install Visual Studio Code](#1-install-visual-studio-code)
2. [Install the PlatformIO IDE extension](#2-install-the-platformio-ide-extension)
3. [Download (get) the project](#3-download-get-the-project)
4. [Open the project in VS Code](#4-open-the-project-in-vs-code)
5. [Build (compile) the firmware](#5-build-compile-the-firmware)
6. [Connect the board and find its port](#6-connect-the-board-and-find-its-port)
7. [Upload (flash) over USB](#7-upload-flash-over-usb)
8. [Open the serial monitor](#8-open-the-serial-monitor)
9. [First-time configuration](#9-first-time-configuration)
10. [Later updates over Wi-Fi (OTA)](#10-later-updates-over-wi-fi-ota)
11. [Command-line quick reference](#11-command-line-quick-reference)
12. [Troubleshooting](#12-troubleshooting)

> **Just want to flash a prebuilt binary?** You don't need any of this — a
> precompiled image is on the Releases page. Jump to
> **[Flash a prebuilt binary (no build environment needed)](#flash-a-prebuilt-binary-no-build-environment-needed)**.

> **What is this?** The gateway is the ESP32-S3 controller that drives the RS-485
> split-flap bus and serves the web UI. This is a [PlatformIO](https://platformio.org/)
> project (see `platformio.ini`). PlatformIO downloads the ESP32 toolchain and every
> required library **automatically** on the first build — you do not install board
> packages or libraries by hand.
>
> Building from the **Arduino IDE is no longer supported** — there is no `.ino` sketch,
> and all board settings live in `platformio.ini`. This guide is the supported path.

> **Target hardware:** Waveshare **ESP32-S3-RS485-CAN** (ESP32-S3, 16 MB flash,
> OPI PSRAM), connected to your computer with a **USB-C data cable** (some cables
> are charge-only — if the board never appears as a serial port, try another cable).

---

## Flash a prebuilt binary (no build environment needed)

If you just want to run the firmware and don't care about compiling from source, you
**don't need VS Code, PlatformIO, or any of the steps below**. A precompiled image is
published on the project's **[Releases](https://github.com/avandeputte/SplitFlapGateway/releases)**
page — download it and flash it directly. Pick the case that matches your board:

- **The board already runs this gateway firmware (just updating)** — download the
  **app image** (e.g. `firmware.bin`) and upload it through the gateway's built-in
  web updater: web UI ▸ **Settings ▸ Open Firmware Updater →** (or browse to
  `http://<gateway-ip>/ota`). No tools to install at all. See
  [Later updates over Wi-Fi (OTA)](#10-later-updates-over-wi-fi-ota).

- **A blank / brand-new board (first flash, over USB)** — download the **full-flash
  image** (e.g. `firmware.factory.bin`, which bundles the bootloader + partition
  table + app) and write it with a **browser-based flasher** — nothing to install:
  1. Open the Espressif **ESP web flasher**: <https://espressif.github.io/esptool-js/>
  2. Plug the board in with a USB-C **data** cable and click **Connect**, then choose
     its serial port.
  3. Add the file at **flash address `0x0`**, select `firmware.factory.bin`, and click
     **Program**.
  4. If it won't start programming, put the board in download mode first: hold
     **BOOT**, tap **RESET**, release **BOOT**, then retry.

  Prefer a terminal? [`esptool`](https://github.com/espressif/esptool) does the same:
  ```bash
  esptool --chip esp32s3 write_flash 0x0 firmware.factory.bin
  ```
  > Use `firmware.factory.bin` (full flash) at `0x0` for a blank board. The plain
  > `firmware.bin` is the **app-only** image — that one is for the OTA updater, not a
  > bare-board USB flash.

After flashing, continue from [§9 First-time configuration](#9-first-time-configuration).

> **Web updater failed part-way?** Nothing was flashed and the old firmware is still
> running. The README's
> [recovery without developer tools](README.md#if-the-web-update-fails--recovery-without-developer-tools)
> section covers the three no-toolchain ways forward, including a USB flash that keeps
> your settings (app image at `0x10000` **plus** `boot_app0.bin` at `0xE000`).

**Everything below is only needed if you want to build from source.**

---

## 1. Install Visual Studio Code

Download and install VS Code for your operating system:

- **All platforms:** <https://code.visualstudio.com/Download>
  - **Windows:** run the `VSCodeUserSetup-x64-*.exe` installer.
  - **macOS:** download the `.zip`, unzip, and drag **Visual Studio Code.app** into
    `/Applications`. (Or `brew install --cask visual-studio-code`.)
  - **Linux:** install the `.deb`/`.rpm`, or `sudo snap install code --classic`.

Launch VS Code once to confirm it opens.

---

## 2. Install the PlatformIO IDE extension

1. In VS Code, open the **Extensions** view: click the squares icon in the left
   Activity Bar, or press **Ctrl+Shift+X** (**Cmd+Shift+X** on macOS).
2. Search for **PlatformIO IDE**.
3. Click **Install** on the entry published by **PlatformIO**.
4. Wait for it to finish — the first install downloads a small Python core and can
   take a few minutes. When prompted, allow it to install and **reload the window**.
5. You'll know it's ready when a small **PlatformIO** (alien-head 👽) icon appears in
   the left Activity Bar and a row of icons (✓ build, → upload, 🔌 monitor, 🗑 clean)
   appears in the bottom status bar.

> PlatformIO needs internet access on the first build to download the ESP32
> platform and libraries. After that, builds work offline.

---

## 3. Download (get) the project

Pick **one** of the following.

### Option A — Clone with Git (recommended; makes updates easy)

1. Install Git if you don't have it: <https://git-scm.com/downloads>.
2. Open a terminal and run:
   ```bash
   git clone https://github.com/avandeputte/SplitFlapGateway.git
   ```
3. The gateway firmware lives in the versioned subfolder **`SplitFlapGateway/2.0`**.

### Option B — Download a ZIP

1. On the project's GitHub page, click **Code ▸ Download ZIP**.
2. Unzip it somewhere permanent (not your Downloads folder).

> **Avoid OneDrive / iCloud / Dropbox synced folders.** Cloud sync can lock files
> mid-build and cause random compile errors. Use a local path such as
> `~/Projects/SplitFlapGateway` or `C:\dev\SplitFlapGateway`.

---

## 4. Open the project in VS Code

PlatformIO identifies a project by the folder that **directly contains
`platformio.ini`**. For this repo that is the **`2.1`** folder.

1. In VS Code: **File ▸ Open Folder…**
2. Select the **`SplitFlapGateway/2.0`** folder (the one with `platformio.ini`,
   `src/`, and this `SETUP.md` inside it).
   - ⚠️ Do **not** open the parent `SplitFlapGateway` folder — PlatformIO won't find
     `platformio.ini` there and the toolbar will be inactive.
3. If VS Code asks "Do you trust the authors of the files in this folder?", choose
   **Yes, I trust the authors**.
4. The first time you open it, PlatformIO indexes the project (bottom-right shows
   "Configuring project…"). Let it finish.

---

## 5. Build (compile) the firmware

This compiles the code and, on the first run, downloads the ESP32 toolchain and the
two external libraries (`PubSubClient`, `ArduinoJson`) declared in `platformio.ini`.

- Click the **✓ (Build)** icon in the bottom status bar, **or**
- Open the PlatformIO sidebar (👽) ▸ **esp32s3_devmodule ▸ General ▸ Build**, **or**
- Press **Ctrl+Alt+B**.

The first build can take several minutes (toolchain + library download). A successful
build ends with a memory-usage table and:

```
========================= [SUCCESS] Took ... seconds =========================
```

The compiled images are written to `.pio/build/esp32s3_devmodule/` — most importantly
`firmware.bin` (the app image, used later for OTA).

> You do **not** need to change any board settings — every board option
> (PSRAM, 16 MB flash, the 3 MB-app/9.9 MB-FATFS partition scheme, USB mode,
> CPU speed, etc.) is already encoded in `platformio.ini`.

---

## 6. Connect the board and find its port

1. Plug the board into your computer with a **USB-C data cable**.
2. Identify the serial port:

   | OS | Port looks like | How to list |
   |---|---|---|
   | **macOS** | `/dev/cu.usbmodem*` (e.g. `/dev/cu.usbmodem114101`) | `ls /dev/cu.*` or `pio device list` |
   | **Linux** | `/dev/ttyACM0` or `/dev/ttyUSB0` | `pio device list` |
   | **Windows** | `COMx` (e.g. `COM7`), shown as "USB Serial Device" | Device Manager ▸ Ports, or `pio device list` |

   In VS Code you can run **PlatformIO ▸ Devices** (👽 sidebar) or, from the PlatformIO
   terminal, `pio device list`.

3. **Set the port.** `platformio.ini` currently pins a macOS port:
   ```ini
   upload_port  = /dev/cu.usbmodem114101
   monitor_port = /dev/cu.usbmodem114101
   ```
   Do one of the following so it matches **your** machine:
   - **Easiest / most portable:** comment both lines out (add a `;` at the start of
     each). PlatformIO then **auto-detects** the board:
     ```ini
     ; upload_port  = /dev/cu.usbmodem114101
     ; monitor_port = /dev/cu.usbmodem114101
     ```
   - **Or** replace the value with your actual port (e.g. `COM7` on Windows).

   > Tip: to keep these machine-specific tweaks out of the tracked file, you can put
   > them in a local, git-ignored `platformio_override.ini` instead.

4. **Linux only — serial permissions.** If uploads fail with "permission denied",
   add yourself to the `dialout` group once and log back in:
   ```bash
   sudo usermod -a -G dialout $USER
   ```

> **Drivers:** the ESP32-S3 uses **native USB** (it appears as a USB CDC serial
> device), so no CH340/CP210x driver is normally required on modern macOS, Linux, or
> Windows 10/11.

---

## 7. Upload (flash) over USB

This builds (if needed) and writes the firmware to the board.

- Click the **→ (Upload)** icon in the bottom status bar, **or**
- PlatformIO sidebar (👽) ▸ **esp32s3_devmodule ▸ General ▸ Upload**, **or**
- Press **Ctrl+Alt+U**.

PlatformIO compiles, then `esptool` connects at 921600 baud, erases the app region,
writes the image, and the board reboots into the new firmware. Success ends with:

```
Hard resetting via RTS pin...
========================= [SUCCESS] ...
```

### If the upload can't connect to the board

Most ESP32-S3 boards auto-enter the bootloader, but if `esptool` reports
*"Failed to connect / No serial data received / wrong boot mode"*, force it into
download mode manually:

1. Press and **hold** the **BOOT** button.
2. Tap (press and release) the **RESET / EN** button.
3. **Release BOOT.**
4. Start the Upload again.

After flashing, press **RESET** (or unplug/replug) to run the firmware normally.

> **First flash must be over USB.** Once a build is running, you can do every later
> update [over Wi-Fi](#10-later-updates-over-wi-fi-ota) — no cable needed.

---

## 8. Open the serial monitor

To watch boot logs and the periodic `[WDG]` diagnostics (115200 baud):

- Click the **🔌 (Serial Monitor)** icon in the bottom status bar, **or**
- PlatformIO sidebar (👽) ▸ **esp32s3_devmodule ▸ General ▸ Monitor**, **or**
- run `pio device monitor` in the PlatformIO terminal.

You should see something like:

```
[Boot] Split-Flap Gateway v3.4.0
[Boot] reset=... heap=... psram=8388608 flash=16384KB sdk=...
[WDG] up=30s heap=... mqtt=1 mods=11 ...
```

Press **Ctrl+C** to stop the monitor. (Only one program can hold the port at a time —
close the monitor before uploading, or just use Upload, which handles the port for you.)

---

## 9. First-time configuration

The board has no Wi-Fi credentials yet, so it starts its own access point.

1. On a phone or laptop, join the Wi-Fi network **`Split-Flap-GW`** (password
   **`12345678`**).
2. Open **<http://192.168.4.1>** in a browser.
3. Go to **Settings ▸ Wi-Fi**, enter your network's SSID and password, and **Save Wi-Fi**.
4. The gateway joins your network; its IP appears on the **Status** page (and in
   the serial log). After that it's reachable on your LAN at that IP or at
   **<http://splitflap-gw.local>** (mDNS).

For provisioning modules, calibration, MQTT, etc., see the [README](README.md) and
[CALIBRATION_GUIDE](CALIBRATION_GUIDE.md).

---

## 10. Later updates over Wi-Fi (OTA)

After the first USB flash you can update without a cable.

### A. Browser upload (simplest)

1. **Build** the firmware in VS Code (step 5).
2. The image you upload is **`.pio/build/esp32s3_devmodule/firmware.bin`**.
   - This is the plain **application image** — what the OTA updater writes to the app
     partition.
   - ⚠️ **Do not** upload `firmware.factory.bin` — that's the full-flash
     (bootloader + partitions + app) image for USB/esptool only, **not** an OTA image.
3. In the gateway web UI: **Settings ▸ Open Firmware Updater →** (or browse to
   `http://<gateway-ip>/ota`).
4. Select `firmware.bin`, click **Upload Firmware**.
5. The gateway reboots on success — confirm the version badge in the header.

> The image is written to the *inactive* partition, so a failed/interrupted OTA
> leaves your current firmware running and intact.

### B. OTA from the command line / PlatformIO (optional)

The board advertises over mDNS as `splitflap-gw`. You can push `firmware.bin` with
`espota`:

```bash
# from .pio/build/esp32s3_devmodule/
python3 -m espota -i splitflap-gw.local -f firmware.bin
# with an OTA password set in Settings:
python3 -m espota -i 192.168.1.105 -a yourpassword -f firmware.bin
```

To make PlatformIO's **Upload** target the board over Wi-Fi instead of USB, set in
`platformio.ini` (or a local override):

```ini
upload_protocol = espota
upload_port     = splitflap-gw.local   ; or the gateway IP
; upload_flags  = --auth=yourpassword  ; if an OTA password is set
```

---

## 11. Command-line quick reference

PlatformIO Core (`pio`) is installed with the extension. Open the PlatformIO
terminal (👽 sidebar ▸ **Quick Access ▸ Miscellaneous ▸ New Terminal**) and run these
from the `2.1` folder:

```bash
pio run                  # build (compile) the firmware
pio run -t upload        # build + flash over USB
pio run -t monitor       # open the serial monitor (115200)
pio run -t upload -t monitor   # flash, then immediately monitor
pio device list          # list serial ports / connected boards
pio run -t clean         # remove build artifacts
pio pkg update           # update platform + libraries
```

> If `pio` isn't on your PATH in a plain system terminal, use the bundled copy:
> macOS/Linux `~/.platformio/penv/bin/pio`, Windows
> `%USERPROFILE%\.platformio\penv\Scripts\pio.exe`.

---

## 12. Troubleshooting

| Symptom | Fix |
|---|---|
| PlatformIO toolbar/icons are missing or greyed out | You opened the wrong folder. Open the **`2.1`** folder that contains `platformio.ini` (step 4). |
| First build fails downloading the platform/toolchain | Check internet access/proxy/VPN and rebuild; PlatformIO needs the network only on the first build. |
| Upload: *"could not open port" / "port is busy"* | Close the **Serial Monitor** (it holds the port), then upload. Only one program can use the port at a time. |
| Upload: *"Failed to connect to ESP32-S3"* | Force bootloader mode: hold **BOOT**, tap **RESET**, release **BOOT**, upload again (step 7). |
| No serial port appears at all | Use a **data** USB-C cable (not charge-only), try another port/cable, and confirm the board has power. |
| Wrong/auto port chosen | Set `upload_port`/`monitor_port` in `platformio.ini` to your port, or comment them out for auto-detect (step 6). |
| Linux: *"permission denied"* on the port | `sudo usermod -a -G dialout $USER`, then log out and back in (step 6). |
| Monitor shows nothing / garbage after boot | Ensure the monitor is at **115200** baud (it's preset in `platformio.ini`); press **RESET** to re-print the boot banner. |
| OTA upload rejected or bricks behavior | Make sure you uploaded **`firmware.bin`**, not `firmware.factory.bin` (step 10). |

---

Need the bigger picture (architecture, REST API, MQTT, module provisioning,
calibration)? See [README.md](README.md), [ARCHITECTURE.md](ARCHITECTURE.md), and
[CALIBRATION_GUIDE.md](CALIBRATION_GUIDE.md).

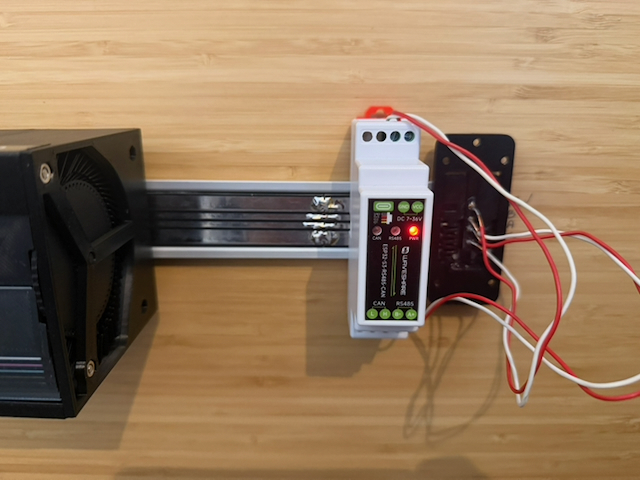
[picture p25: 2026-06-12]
screenshots/TotallyJankyWiringPicture.jpeg

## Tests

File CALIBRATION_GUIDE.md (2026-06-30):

# Module Calibration Guide

How to calibrate a split-flap module from the gateway's web UI — for a brand-new
module, a module whose **home position is wrong** (the blank flap isn't centered),
or a module where **one or more characters land off-center**.

Everything here is done from the **Calibration** tab of the gateway web UI. No
serial console or special tools are required.

---

## Before you start

**What calibration actually controls.** Each module stores three things in its
own EEPROM:

- **Total Steps** — how many motor steps make one full revolution of the reel.
  This is the single most important value: every flap position is derived from
  it. The factory default is `4096`, but the true value of a given reel can be
  slightly different (e.g. `4097`) or substantially different on other hardware.
- **Home Offset** — how many steps past the hall-sensor trigger the reel must
  move to land the blank flap (index 0) centered in the window. Default `2832`.
- **Character Map** — an optional per-flap fine-tune. For each flap the module
  can store a custom step position. If a flap has no custom value, the module
  computes its position as `(index × Total Steps) / flap count` — the flap count
  is 64 by default, or the module's configured count on firmware v31+.

**The golden order.** Always calibrate in this order, because each step depends
on the one before it:

1. **Total Steps** (Count Steps) — sets the scale everything else is measured in.
2. **Home Offset** — centers the blank flap so the whole reel is aligned.
3. **Individual characters** — only the few flaps that still land off after 1–2.

Doing them out of order wastes effort: if you hand-tune characters and *then*
change Total Steps, all the default positions shift and you may have to redo your
work.

> **Turn on Maintenance mode first.** Calibration physically spins the reels.
> If an external system sends a display command over MQTT mid-calibration, it
> can move a reel while you're working on it. A yellow reminder with a **Turn On
> Maintenance** button sits at the top of the Calibration tab — click it before
> you begin. The reminder disappears once Maintenance is on. The web UI keeps
> working normally in Maintenance mode; only MQTT-sourced commands are ignored.
> Turn Maintenance back off when you're done.

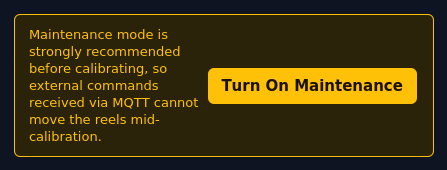
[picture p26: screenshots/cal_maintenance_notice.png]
Maintenance mode reminder at the top of the Calibration tab


---

## Step 0 — Select the module

1. Open the **Calibration** tab.
2. The grid mirrors your display layout (one cell per module position, IDs `0`
   to rows×cols−1). Cells are color-coded:
   - **Green border** — a known module (modern firmware, has a serial number).
   - **Yellow border / "v7"** — a legacy module (firmware v7 or earlier). These
     have no serial number and can't be provisioned or factory-reset, but they
     fully support homing and calibration.
   - **Dimmed** — not yet seen on the bus.
3. Click the module you want to calibrate. If it isn't in the grid (e.g. an ID
   outside the configured layout), type it into **"or tune any ID"** and press
   **Go**.

The detail card opens showing the module's current **Home Offset** (green) and
**Total Steps** (yellow), read live from its EEPROM, plus the **Character Map**.

> If a value looks stale, click **Re-read EEPROM** at the top of the card to
> fetch a fresh copy from the module.

---

## Step 1 — Measure Total Steps (Count Steps)

Do this first on any new module, and any time the reel has been mechanically
changed.

1. Click **Count Steps** (next to the Total Steps field) — or the **Calibrate**
   button in the "New module?" notice; they do the same thing.
2. Confirm the prompt. The reel will **spin a full revolution** to measure
   itself. This takes a few seconds (up to ~15s); the button shows "Counting…"
   while it works.
3. When it finishes, the measured steps/rev appears in the **Total Steps** field
   and is saved to the module's EEPROM automatically. The status line reads
   "Total steps measured and saved: N."

You normally never type Total Steps by hand — let **Count Steps** measure it. The
**Save** button next to the field is there if you ever need to enter a known
value manually, and **Revert** resets it to the firmware default (`4096`).

---

## Step 2 — Fix the home position (blank flap not centered)

After homing, flap 0 (the blank/black flap) should sit centered in the window.
If it's high or low, the **Home Offset** is off. There are two ways to adjust it;
use whichever you prefer.

### Option A — Nudge live (easiest)

The nudge row (`−32 −16 −4 −1 / +1 +4 +16 +32`, labeled **NUDGE OFFSET**) moves
the reel **and** saves the new offset **instantly** with each press.

1. Watch the physical reel.
2. Press a nudge button. The reel moves by that many steps and the offset is
   saved immediately.
   - Use the big steps (±16, ±32) to get close, then ±1/±4 to fine-tune.
3. When the blank flap is centered, click **Home Motor** to re-home and confirm
   it lands correctly.

Because nudge saves instantly, there's no separate save step — what you see is
what's stored.

### Option B — Set an exact offset

If you already know the offset value you want:

1. Type it into the **Home Offset** field.
2. Click **Save**. (Unlike nudge, this sets the value but does **not** move the
   reel.)
3. Click **Home Motor** to re-home and verify.

To start over, click **Revert** next to Home Offset to reset it to the default
(`2832`), then re-home and re-nudge.

> **Always finish with Home Motor.** The offset only takes visible effect after
> the reel re-homes. If you adjust and don't re-home, the flap won't appear to
> move.

---

## Step 3 — Fix individual characters

Once Total Steps and Home Offset are right, most flaps will land correctly on
their own, because the module computes each position from Total Steps. Only tune
the specific characters that are still visibly off-center.

### Reading the Character Map

Each cell shows a character (or a colored swatch for the 7 color flaps, or a
black square for the blank) and its current step position:

- **Grey value** — the flap is using the computed firmware default
  (`(index × Total Steps) / 64`). Nothing custom is stored.
- **Green value / green border** — a custom position is stored in EEPROM for this
  flap.

### Tuning one character

1. Click the character's cell. The **Tune** dialog opens, showing the character,
   its **Default** position, and (if one exists) its **Current EEPROM** value.
   The **Absolute Target Step** field starts at the current value.
2. Click **Test Position (GOTO)**. The reel moves to that step so you can see
   exactly where the flap lands. *This is a test only — it does not save.*
3. Adjust the target and test again until the flap is centered:
   - Use the nudge buttons in the dialog (`−32 … +32`) to change the **Absolute
     Target Step** value. These **only edit the number** — they do not move the
     reel or save anything.
   - After each adjustment, press **Test Position (GOTO)** again to see the new
     spot.
   - Repeat *Test → adjust → Test* as many times as you like.
4. When the flap lands perfectly, click **Lock to EEPROM**. The position is saved
   and the cell turns green (custom).

### Reverting a character to its default

If you want a flap to go back to using the computed default (for example, you
tuned it by mistake, or you re-measured Total Steps and want it recalculated):

1. Open the character's Tune dialog.
2. Click **Revert to Default**.

This **unsets** the custom value in the module's EEPROM (it's cleared, not
overwritten with a number), so the module goes back to computing the position
from Total Steps. The cell returns to grey.

---

## The Calibration Wizard (guided, recommended)

Steps 1–3 above can all be done by hand, but the **Calibration Wizard** walks you
through the entire process automatically: it steps through every flap one at a
time, moves the reel to each one so you can see it, and lets you confirm or adjust
each before saving. It's the easiest way to do a full pass on a new module. The
Wizard and the Character Map follow the module's own character order and flap
count (its custom flap set on firmware v31+, or the default 64-flap reel otherwise).

Start it from the **Calibration Wizard (step through all flaps)** button under the
Character Map.

### The wizard checks your prerequisites first

Because every flap position depends on the step count and home offset, the wizard
asks about both before it begins.

**1 of 2 — Step count.** Confirms you've measured this reel's true steps per
revolution. If you haven't, choose **No — run Calibrate now** and it runs Count
Steps for you; re-open the wizard when it finishes.

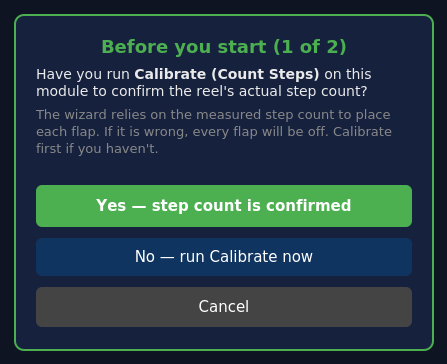
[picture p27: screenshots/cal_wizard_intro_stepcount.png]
Wizard step 1 of 2: confirm the step count has been measured


**2 of 2 — Home position.** Confirms the blank (black) flap is centered when
homed — this is the home offset. If you're not sure, choose **Confirm / adjust
home position now**.

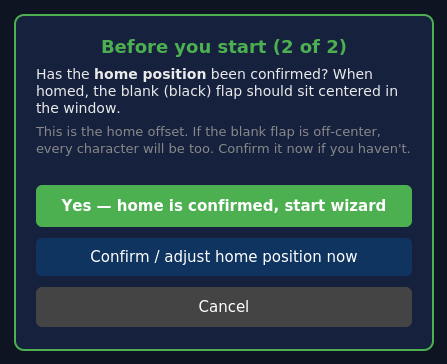
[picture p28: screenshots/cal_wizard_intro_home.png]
Wizard step 2 of 2: confirm the home position


**Confirming the home position.** This homes the reel and shows the blank flap.
Use the nudge buttons until the black flap is centered in the window — each nudge
moves the reel and **saves the home offset instantly**. Press **Re-home (verify)**
to re-home and check, then **Home is centered — start wizard** to continue.

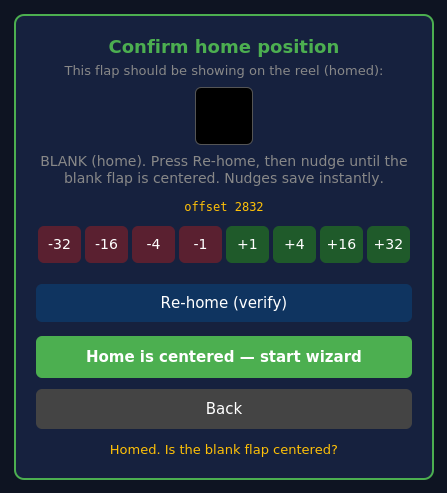
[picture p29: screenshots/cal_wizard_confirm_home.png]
Wizard home-position confirmation showing the black blank flap and nudge controls


### Stepping through the flaps

For each flap, the wizard moves the reel to that character and shows you which one
*should* be displayed:

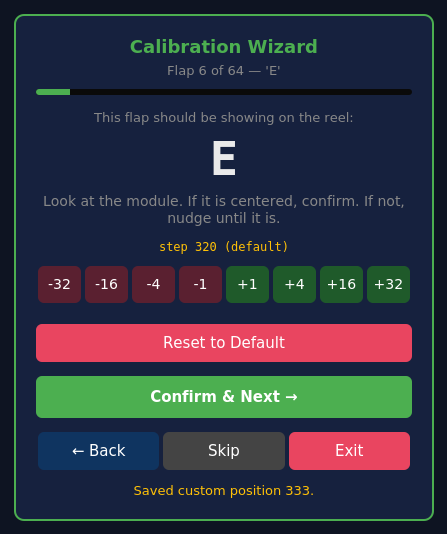
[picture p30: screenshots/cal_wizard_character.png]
Wizard per-character screen: expected character, target step, nudge buttons, and confirm/reset/skip/back/exit controls


- Look at the module. If the shown character is centered, click **Confirm &
  Next** to save it and advance.
- If it's off, use the **nudge buttons** (`−32 … +32`). Each nudge moves the reel
  so you can see the change. Adjust until centered, then **Confirm & Next**.
- **Reset to Default** returns this flap to its computed default position and
  clears any custom value — useful if a previous tune was wrong.
- **Skip** advances without saving. **← Back** revisits the previous flap.
  **Exit** stops the wizard (flaps you already confirmed stay saved).

### What gets saved

The wizard keeps the module's EEPROM tidy:

- A flap you **adjusted** away from its default is saved as a **custom** position
  (it turns green in the map).
- A flap that was **already correct** at its default is left as a computed default
  (stays grey) — so if you re-measure Total Steps later, it recalculates
  automatically.
- A flap that **had** a custom value but you reset/nudged back to the default has
  its custom value **cleared**.

The status line under each flap tells you exactly what happened ("Saved custom
position 333", "Already at default — no change needed", and so on). When you reach
the last flap, the wizard closes and refreshes the Character Map.

### Calibrating the whole board at once

The per-module wizard above is the way to dial in one module. When you're
checking or correcting an **entire wall**, the **Calibrate Whole Board** button
(in the same **Calibration** section) is faster: it steps *every* module to the
same flap at once, so you walk the wall one character at a time instead of one
module at a time.

For each flap, every module is told to show that character (a single broadcast,
so each module uses its own saved map). Look across the wall:

- Modules that are correct need nothing — move on with **Next**.
- For any module that's **off**, click its cell in the grid. That loads the
  module and opens the same per-character nudge dialog used everywhere else;
  adjust until centered and the fix is saved to that module. The cell turns green
  to mark it fixed.
- **Prev / Next** move between flaps, and you can jump straight to a specific
  flap. **Finish** ends the pass.

Because it reuses the single-module tuning dialog, corrections behave identically
(same nudge steps, same custom-vs-default save rules as above). The whole-board
wizard also leaves **Maintenance mode exactly as it found it** — if maintenance
was off when you started, it's turned back off when you finish.

A cell flagged **DUP?** means two modules may share that ID; nudging it could move
or save the wrong module, so the wizard asks you to confirm before correcting it.
Resolve duplicate IDs (deprovision and reassign) before relying on a whole-board
pass.

---

## Typical workflows

### A brand-new module

The quickest path is the **Calibration Wizard**, which handles all of this in one
guided flow:

1. Turn on **Maintenance** mode.
2. Select the module.
3. Click **Calibration Wizard**. When it asks, run **Calibrate** (step count) and
   confirm the **home position** in the intro steps.
4. Step through the flaps, confirming or nudging each.
5. Turn **Maintenance** back off.

Or do it manually:

1. Turn on **Maintenance** mode.
2. Select the module.
3. **Count Steps** to measure and save Total Steps.
4. Click **Home Motor**; if the blank flap isn't centered, **nudge** the Home
   Offset until it is, then **Home Motor** again to confirm.
5. Send a few test characters (from the Display tab) and tune any flaps that land
   off-center using the Character Map.
6. Turn **Maintenance** back off.

### "The home position is wrong" (blank flap off-center)

1. Maintenance on → select the module.
2. Click **Home Motor** to see the current home.
3. **Nudge** the Home Offset (Step 2A) until the blank flap is centered, re-home
   to confirm.
4. Maintenance off.

If homing is *wildly* off (not just a small offset), the Total Steps value is
probably wrong — run **Count Steps** (Step 1) first, then redo the offset.

### "One or more characters are wrong" but the blank flap is fine

1. Maintenance on → select the module.
2. Confirm Home Offset is good (blank flap centered after **Home Motor**). If the
   blank is fine but *every* character is progressively more off the further it
   is from blank, that's a **Total Steps** problem — run **Count Steps** and
   recheck before tuning individual flaps.
3. For each wrong flap: click its cell → **Test Position (GOTO)** → adjust →
   **Lock to EEPROM** (Step 3).
4. Maintenance off.

> **Rule of thumb:** if only a *few scattered* flaps are off, tune them
> individually. If *all* flaps drift more the farther they are from blank, fix
> **Total Steps** first — one measurement corrects them all at once.

---

## Quick reference

| Control | What it does | Saves? | Moves reel? |
|---|---|---|---|
| **Count Steps** | Measures steps/revolution and stores it | Yes | Yes (1 rev) |
| **Total Steps → Save** | Stores a hand-entered steps/rev | Yes | No |
| **Total Steps → Revert** | Resets to default `4096` | Yes | No |
| **Nudge Offset (±)** | Adjusts home offset live | Yes (instant) | Yes |
| **Home Offset → Save** | Stores an exact offset | Yes | No |
| **Home Offset → Revert** | Resets to default `2832` | Yes | No |
| **Home Motor** | Re-homes the reel (verifies the offset) | — | Yes |
| **Test Position (GOTO)** | Moves to a step to preview a flap | No | Yes |
| **Tune dialog nudge (±)** | Edits the target step number only | No | No |
| **Lock to EEPROM** | Saves a custom position for that flap | Yes | No |
| **Revert to Default** | Clears the custom position (uses computed default) | Yes | No |
| **Calibration Wizard** | Guided pass through all 64 flaps | per flap | Yes |
| **Wizard: Confirm & Next** | Saves the flap (smartly) and advances | Yes | No |
| **Wizard: nudge (±)** | Adjusts the flap and moves the reel to show it | No (until confirm) | Yes |
| **Wizard: Reset to Default** | Returns the flap to its computed default | Yes | Yes |
| **Wizard: Skip / Back / Exit** | Navigate without saving | No | No |

---

## Tips & troubleshooting

- **Re-read EEPROM** any time you want to confirm what's actually stored on the
  module versus what's on screen.
- **A value won't "stick"?** Make sure you clicked **Save** (or **Lock to
  EEPROM** in the tune dialog). The only control that saves automatically is the
  **Nudge Offset** row.
- **Nothing moves after changing the offset?** The offset only shows after the
  reel re-homes — click **Home Motor**.
- **The whole reel is off by a consistent amount** → Home Offset. **The error
  grows the farther a flap is from blank** → Total Steps. **Just a few random
  flaps are off** → tune those characters individually.
- **Legacy (v7) modules** calibrate exactly the same way — Count Steps, Home
  Offset, and per-character tuning all work. They simply can't be provisioned or
  factory-reset.
- **Don't forget to turn Maintenance mode back off** when you finish, or the
  display will stop responding to MQTT commands.

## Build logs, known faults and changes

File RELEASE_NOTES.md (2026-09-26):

# Split-Flap Gateway — Release Notes

## v3.13.1 — 2026-09-25

### Fixed

- **A Quiet Time schedule could reboot the gateway -- and with Restore on Boot enabled, loop.**
  The schedule was evaluated on the RTC task, which has a 2 KB stack that already peaks at
  about 1.4 KB just reading the clock. Asserting Quiet Time from there sends bus frames through
  a call chain (`sfSetQuietTime` → `sfHome` → `rs485Send` → `mqttPublishMsg`, plus `printf`)
  that needs roughly 1.5 KB more: a stack overflow, a panic, a reboot. Reported as "quiet time
  does not work with restore on boot: it goes blank, after a minute it loads the backup, and
  loops" -- exactly that sequence: power-up homing (blank), the boot restore, the schedule
  asserting quiet the moment the restore released the bus, the crash, and round again. The
  schedule now ticks on the network task, which has the stack for it.
- **Restore on Boot now takes the bus before any task starts.** It used to be armed after the
  tasks were spawned, so the first schedule tick could assert Quiet Time in the gap and the
  restore then ran under it (its final home-all suppressed).

## v3.13.0 — 2026-09-23

### Added

- **A default step-pacing setting (`stepMs`).** Settings ▸ *Display Layout* gains *Default step
  pacing (ms)*, stored in NVS and reported as `stepMs` on `GET /api/config` (set it with
  `POST /api/config/settings {"stepMs":25}`, 0–100, default 15). The companion (v2.10.22+)
  reads it as its default `step_ms` -- the per-module gap every app page send and Compose
  inherit -- so the pacing a wall needs lives with the wall, not in each client. Larger walls
  need slower pacing: measured on 60 modules, 15 ms lost 27, 20 ms lost 9, 25 ms was stable.
  The gateway stores and reports the value; it does **not** pace its own sends by it.

### Changed

- The per-request `step_ms` cap on `/api/rs485/batch` and `/api/display/cells` is raised from
  30 to 100 ms to match, so a stored default above 30 is honoured rather than silently clamped.

## v3.12.1 — 2026-09-14

### Fixed

- **Display layouts of more than about 50 cells broke the Display and Calibration tabs**
  ("Could not load display state", "Error loading layout"). `GET /api/display/state` streams
  its cell list in 256-byte batches, and every batch but the last was sent without a string
  terminator, so stale bytes leaked into the JSON at each batch boundary. A small wall fits in
  one batch and never hit it; a 6 × 20 wall did on every poll. The batch is now terminated
  before each flush. No other endpoint had the flaw (the module list streamer already
  terminated its chunks).

## v3.12.0 — 2026-09-01

**Restore on boot.** A calibration backup can now live on the gateway and be replayed to
every module on every boot — for walls whose modules lose or corrupt their EEPROM, or get
swapped around. The backup is the source of truth; every power cycle puts the wall back.

### Added

- **Restore on Boot** (Settings tab) — upload a backup file (the one *Backup Calibration*
  produces) to the gateway, tick *Restore calibration on every boot*, set the post-boot delay
  (default 10 s, so the modules finish their own auto-home first), and Save. A run writes each
  module by serial number (`mXW`, the same frame `/api/flap/restorebysn` sends, then a fixed
  gap for the EEPROM write), re-provisions it (`mXI`) when the backup's ID differs from the one
  the gateway knows, reads every module back (`mXA` on v25+, `mXD` on v15+, `m<id>d` below
  that) and compares home offset, steps per revolution, every flap position and the v31+ flap
  set, re-writes and re-reads anything that differed or did not answer once, then homes the
  wall. **Run Restore Now** does the same without a reboot; **Cancel Restore** stops a run
  after its current step.
- **The bus is locked for the whole run.** From boot (or the moment *Run Restore Now* is
  pressed) until the run ends, every REST endpoint that would touch the RS-485 bus answers
  `503 {"error":"restore in progress"}` and MQTT commands are dropped; the maintenance switch
  and all read-only, settings, status and OTA endpoints keep working. The gateway's own
  background bus traffic (flap-set trickle, stale-module probes, the quiet-time schedule)
  pauses. The dashboard shows a red border and a banner with the phase and progress.
- **It always finishes.** Every wait is bounded and a module that never answers is counted as
  *not answering*, so a missing module can never leave the gateway locked. A restore that
  cannot start (enabled, but nothing usable stored) is logged and skipped without locking.
- REST: `GET /api/restore` (setting, stored file, run progress and counters),
  `PUT /api/restore/backup` (validated before it is accepted, atomic, max 256 KB),
  `DELETE /api/restore/backup`, `POST /api/restore/run`, `POST /api/restore/cancel`;
  `restoreOnBoot` / `restoreDelay` on `GET /api/config` and `POST /api/config/settings`;
  a `restore` object (`state`, `done`, `total`, `startsIn`) on `GET /api/status`.
- The stored backup lives in FATFS as `/restore.bak` (temp file + rename, survives OTA).
- **The module registry is permanent.** A module is never removed for being quiet. One not
  heard from in 24 hours is re-queried (a version query, a few per minute) so its record stays
  current; after four unanswered queries it is left alone for an hour and asked again. Only
  Identify All, De-provision, or a corrupt record removes an entry, so the module list and
  `GET /api/capabilities` are complete from the first second after boot.

### Fixed

- **Browser OTA no longer dies near the end of a full-size image.** The upload callback set the
  CORS header on every received chunk, and `WebServer::sendHeader()` keeps each call as a
  heap-allocated node until the response goes out -- ~1000 chunks ate ~80 KB of a 100 KB heap,
  the connection reset at 1.2-1.3 MB with min-free heap under 1 KB, and nothing was flashed
  (the browser's instant "100 %" is the file leaving the browser, not arriving). The header is
  now set once, on the response. A 1.48 MB image uploads in ~10 s with 80 KB of heap to spare,
  and the `/ota` page now waits for the gateway to come back and names the version it booted.

### Changed

- **A restore writes the flap map entry by entry**, not inside the `mXW` frame. A module writes
  each entry to EEPROM as it parses it and cannot keep up with a long frame at line speed: on
  v31 firmware a 434-byte restore frame left 20 of 42 entries and the module was deaf for ~6 s
  afterwards. The boot restore now sends `mXW` with offset, steps and flap set (which clears
  the map), waits for that erase, then one short `m<id>w<i>:<p>` per entry, paced — the
  wizard's own frames. **`POST /api/flap/restorebysn` and the Settings tab's Restore from
  File do the same**: the endpoint sends the `mXW` (offset, steps, flap set), schedules each
  entry as a paced `m<id>w` frame on the RS-485 task (the batch queue, so the web server never
  blocks), and returns at once with `{entries, perEntry, id, settleMs}`; the dashboard waits
  `settleMs` per module before re-provisioning it or moving on. It takes an optional `id`;
  otherwise the registry's id for that serial is used, and only with no id known at all does
  the map go inline as before. The dashboard also drops a flap set whose character count does
  not match its flap count from an old backup instead of writing it.
- **An inconsistent flap-set tail is ignored.** A v31 `A` reply that lost its tail in transit
  can parse as `64:` plus a few characters. That used to land in the registry, in
  `/api/capabilities`, and in backups — and restoring such a backup wrote the truncated set
  into the module. The parser now treats a tail whose character count does not match its flap
  count as "not reported", and the restore neither writes nor verifies such a set.
- `POST /api/flap/restorebysn` builds its frame through the same `sfBuildRestoreFrame()`
  the boot restore uses.
- `Access-Control-Allow-Methods` now also lists `DELETE`.
- **`pio run -e esp32s3_ota -t upload`** — a preconfigured espota environment in
  `platformio.ini` (`default_envs` keeps plain `pio run` on the USB build). The browser
  upload at `/ota` still fails near the end of a full-size image on this board (heap
  exhaustion, the connection resets and nothing is flashed); espota is the path that works.

## v3.8.0 — 2026-07-14

Everything since **v3.4**, summarised. One client can now drive any wall: a new
`GET /api/capabilities` tells it exactly what a wall can show, and a new
`POST /api/display/cells` sets a whole row through the same contract the **Matrix Portal
Gateway** answers — so the companion drives the physical wall and the LED-matrix emulation
identically. Plus quiet-time blanking, a per-board MQTT identity, safer web OTA, and a
security fix.

> **Upgrading from v3.4:** two things to know. If you use the **Home Assistant** integration,
> the device id changes (see below) — delete the old device. And modules re-report their flap
> set to the gateway over the first couple of minutes after boot (the persistence format was
> bumped); nothing you need to do.

### Added

- **`GET /api/capabilities`** — one call that answers *what characters can this wall show?*
  On a real wall the answer is not one set: every module owns its reel, and firmware v31 lets
  each be told a different one, so the response reports `union` (any module can show it),
  `common` (**every** module can — these genuinely differ on a mixed wall), and `sets`: each
  distinct reel once, with the module ids that carry it (`"0-44,50"`). Colour flaps are listed
  by name; modules too old to report a reel appear under `assumed`, ones not yet known under
  `unknown`. **The Matrix Portal Gateway answers the same URL identically**, so a client never
  has to know which kind of wall it is driving.

  To answer it, the gateway now learns each module's flap set from the v31+ `A` reply and
  **persists** it — asking a 45-module wall costs ~90 s of bus time at 9600 baud, so it is
  cached, filled by a slow background trickle, and re-read only when an `N` command changes a
  reel.

- **`POST /api/display/cells`** — set a run of modules in one call: `{ch | color | blank | skip}`
  per cell, named colours, and `step_ms` cascade pacing. The **same JSON contract** the Matrix
  gateway answers. It is *lenient* — a cell this wall cannot show is skipped, not a 400 that
  discards the row (the response reports `sent` vs `skipped`); only structural errors 400.

### Changed

- **The dashboard speaks 13 languages** plus English, chosen from the browser with a Settings
  override and a `?lang=` parameter, all in one firmware image.
- **Quiet Time now blanks the wall.** Entering quiet homes every reel (the *Home All*
  operation); leaving it restores what each module was showing, or the newest request made
  while quiet. Applies to the schedule, the manual switch, REST, MQTT and Home Assistant alike.
- **The Home Assistant re-skin is complete** — every control clears WCAG AA in both light and
  dark themes, and the module cards, status tiles and bus monitor read the palette tokens too.

### Fixed

- **[Security] A remotely-reachable stack buffer overflow is closed.** The by-serial
  flap-config path (`POST /api/flap/flapconfig` with an `sn`, and the MQTT flapconfig topic)
  built its RS-485 frame from an **unvalidated** serial into a fixed stack buffer, so a long
  serial overran it and corrupted the stack. The serial is now validated before it is used.
- **Every gateway now has its own MQTT identity.** The client id and Home Assistant device id
  were derived from a MAC field that is identical on every ESP32, so two boards on one broker
  evicted each other in a loop. They now use the bytes that actually differ. **The HA device id
  changes as a result — delete the old device.**
- **Web OTA no longer reboots the board mid-flash.** A low-heap watchdog fired during the
  upload — which drives heap low on purpose — and reset onto the old image. The watchdog now
  stands down for the duration of an upload. *(Browser OTA on this 16 MB board remains
  heap-tight near the end of a large image; ArduinoOTA/espota is the reliable path.)*
- **Smaller fixes:** the companion-URL save no longer contends with a firmware upload for the
  flash; `/api/capabilities` returns in ~0.03 s (its response is buffered and its scratch lives
  in PSRAM) and its module-id range list can no longer truncate or mis-order; and the
  double-quote flap is reachable by character (`"` maps to the reel's `q`, which is what
  `/api/capabilities` advertises).

---

## v3.6.1 — 2026-07-13

**Every gateway now has its own MQTT identity.** Two of them on one broker used to knock
each other offline, forever.

### Fixed

- **The MQTT client id and the Home Assistant device id were the same on every board.** Both
  were derived from `ESP.getEfuseMac()`'s *low* bytes — but that value is byte-reversed, so
  its low bytes are the Espressif OUI (`48:27:e2`), which is identical on every ESP32 ever
  made. Two gateways both connected as `splitflap-20E22748`, and **an MQTT broker evicts the
  client already holding a duplicate id**, so the pair disconnected each other in a loop. In
  Home Assistant they collapsed into a single device.

  The id now comes from the MAC bytes that actually differ between boards.

  > **If you use the Home Assistant integration, the device id changes** (`sfgw_20E22748` →
  > `sfgw_E2xxxxxx`). Home Assistant will discover a *new* device — delete the old one. The
  > integration is opt-in and off by default, so this only affects you if you enabled it.

  Found the moment a second gateway was put on the same network. It ships in Matrix Portal
  Gateway v1.2.1 too, where it was verified on hardware.

---

## v3.6 — 2026-07-13

**Quiet Time now blanks the wall.**

### Changed

- **Turning Quiet Time on empties the display.** Every reel is homed to its blank flap as
  quiet time begins — the same operation as the **Home All** button — so the wall goes dark
  and silent for the night instead of freezing mid-message.

- **Turning it off puts the wall back.** What each module was showing is snapshotted before
  the blanking, so the existing end-of-quiet resync restores it. If the host asked for
  something newer while quiet, that wins instead — the newest request is what you get.

  This applies to the schedule and to the manual switch alike, wherever quiet is set from:
  the dashboard, REST, MQTT or Home Assistant.

### Fixed

- **The Quiet Time banner could never be translated.** The string extractor rejects any text
  containing a semicolon (a filter meant to screen out CSS and JS), and the banner had one —
  so it was the single piece of UI prose with no catalog entry, silently stuck in English in
  all 13 languages. Its replacement has no semicolon, and is translated.

---

## v3.5 — 2026-07-13

Makes the dashboard **multi-lingual** — 13 languages plus English, picked automatically
from the browser — and **fixes the v3.4 re-skin**, which had left several controls
literally invisible in the light theme.

> **If you are on v3.4, update.** In the light theme (the default) every secondary button
> — **Refresh**, **Identify All**, **Home All**, **Re-read EEPROM** — renders white text on
> a near-white background (1.3:1 contrast). The destructive-action buttons and the bus
> monitor's frame text are unreadable too. It looks perfect in dark mode, which is why it
> shipped.

### New

- **The dashboard speaks your language.** English plus **British and Australian English,
  French, German, Spanish, Italian, Portuguese (Portugal and Brazil), Dutch, Danish,
  Swedish, Norwegian and Finnish** — the languages whose text the flap modules could
  actually display (the Windows-1252 repertoire), so the dashboard and the wall speak the
  same set.

  The language is chosen the same way light/dark already is: **it follows your browser**,
  with nothing to configure. In order: `?lang=fr` in the URL (which lets the companion
  request a language for an embedded view *without* changing your own setting, so it is
  deliberately not saved) → the Settings override → `navigator.languages` → English.
  The gateway stores **no language state at all** — no config field, no NVS write, no API.

  **Every language ships in the one firmware image**; there is no per-language build and
  switching never means reflashing. That is affordable because only the *words* are
  duplicated, not the page: the dashboard is 109 KB of HTML/CSS/JS but only ~11 KB of it is
  English *text*. A dictionary carries the English key alongside each translation, so it
  compresses to about **9 KB** — all 13 languages together cost roughly **115 KB of flash**,
  under 7% of what was free. The browser fetches just the one dictionary it needs
  (`GET /lang/<code>`, gzipped) and **English fetches nothing** — it is the text already in
  the page, which is also the per-key fallback. So a translation can be *partial*, and a
  missing string simply stays English instead of breaking a screen.

  The **bus monitor is never translated** — it shows RS-485 frames and their decode, which
  is protocol, not prose (and its decode labels are padded to keep the columns aligned).

### Fixes

- **The Home Assistant re-skin left half the UI behind — and some of it was invisible.**
  The re-skin re-points the palette tokens in `:root`, which only reaches components that
  *read* a token. Everything that hardcoded the old dark palette stayed dark on the new
  light page, and one token change had a nasty knock-on effect:

  `--acc` went from a solid navy to 12% black, but buttons inherit `color:#fff` from the
  base rule — so **every button that overrode only its background kept white text**. In the
  light theme that is white-on-`#e0e0e0`: **1.3:1, invisible**. It hit the secondary buttons
  (Refresh, Identify All, Home All, Re-read EEPROM), the nudge buttons, Tune's GOTO and the
  wizard's Back. The destructive-action buttons were `#212121` on `#1a0d0d` — **1.2:1**.

  | | before (light) | after |
  |---|---|---|
  | Secondary buttons | 1.3:1 — invisible | **12.2:1** |
  | Destructive buttons | 1.2:1 — invisible | **15.4:1** |
  | Bus-monitor frame text | 1.2:1 — invisible | **15.4:1** |
  | Amber status text | 2.0:1 | **4.9:1** |
  | Green status text | 3.3:1 | **5.1:1** |

  Also themed: the **bus monitor** (its log panel now follows the theme, and its
  RX/TX/REST/MQTT channel colours — chosen for a black panel, and 1.7–3.6:1 on white — got
  per-theme shades), the calibration module picker, character map, edit box, note banner,
  EEPROM map, wizard progress bar and the maintenance banner. `.wall` and `.flap` stay dark
  on purpose: they draw the flap wall.

  Semantic colours were doing double duty as *fills* (buttons/banners, which carry their own
  text colour and were fine) and as *text*, where the fill shades collapse on a white page.
  Text usages now take their own tokens. **Every fixed element clears WCAG AA (≥4.5:1) in
  both themes**, verified by computing contrast rather than eyeballing.

- **Mojibake in the OTA help text** — a mangled em-dash was rendering as `?`.

### Under the hood

- **`src/web_ui.h` is now generated.** The dashboard is built from `ui/index.html` by
  `tools/build_ui.py`, which also embeds the language dictionaries. **Edit `ui/index.html`,
  not `src/web_ui.h`** — the latter is regenerated and your edits would be overwritten.
  `tools/i18n_check.py` validates the dictionaries and `node tools/i18n_test.js` covers the
  language-matching rules.

---

## v3.4 — 2026-07-12

Gives the dashboard the **companion's look**, folds **backup & restore** into the
Settings page, teaches the gateway and the companion to **tell each other which tabs
they have**, and fixes a group of real robustness bugs — most importantly a **web
server that froze during a paced batch** and a **watchdog reboot on large walls**.
Drop-in upgrade: no module, MQTT or wiring changes, and backups themselves are
untouched.

### Changed

- **A new look — the Home Assistant design language.** The dashboard is restyled to
  match the companion (which ships the same look), so the two feel like one product.
  It follows the browser/OS **light or dark** preference; there is no theme setting.
  Purely cosmetic — no control moved or changed behaviour.

- **Backup & restore moved to Settings.** The **Backup Calibration** and **Restore
  Calibration** cards now sit at the end of the Settings page; the **Backup** tab is
  gone. Nothing about the backup format or the restore-by-serial behaviour changed —
  only where the controls live. (The backup file is assembled in the browser from the
  existing module/EEPROM endpoints; restore posts to `/api/flap/restorebysn`.) An old
  `#backup` deep link now lands on Settings rather than breaking.

- **Batch pacing no longer blocks the web server.** `POST /api/rs485/batch` used to
  produce its `step_ms` stagger by **sleeping between frames**, on the web task — and
  the HTTP server handles one connection at a time, so a paced batch froze the whole
  web UI for the length of the cascade (up to the old 8 s cap) while further
  connections piled up in the TCP accept queue holding window buffers. The handler now
  stamps each frame with a due time, hands it to the RS-485 task (which already wakes
  every 5 ms) and returns immediately. The cascade on the wall is unchanged.

  Two contract notes: **`200` now means *accepted*, not *transmitted*** (`sent` counts
  frames accepted), and the 8 s total-pacing cap is replaced by a queue depth of **127
  paced frames in flight**. A frame goes out immediately instead of paced when
  `step_ms` is 0, when it is longer than 48 bytes, or when the queue is full — so a
  cascade beyond 127 paced frames loses its stagger past that point. A whole-page
  redraw is one frame per module, so that only bites above 127 modules.

- **The companion URL is persisted on a debounce.** Two companions pointed at one
  gateway each re-register their own URL on their ~30 s heartbeat, so the stored URL
  flipped back and forth — and saving on every change meant **an NVS write every ~30 s,
  forever** (observed in the wild). The URL now applies to RAM instantly (the tab is
  live at once) but only reaches flash once it has held still for two minutes. A
  contested URL therefore never gets written at all, which is the right answer; a
  companion re-registers within a heartbeat of any reboot, so nothing is lost.

### New

- **Tab advertisement (`POST /api/companion`).** The companion may now send `tabs` —
  the deep links its own UI offers — and the response always carries `gwTabs`, this
  firmware's. Each side then renders the other's real tabs instead of a list hard-coded
  on the far side, which is what made the Backup tab above a two-release problem.

  Both halves are optional and independent, so **every old/new pairing works**: an older
  companion advertises nothing and the dashboard falls back to its built-in companion
  tabs; an older gateway returns no `gwTabs` and the companion falls back to its own list
  (which still includes **Backup**, because a pre-3.4 gateway really does have that tab).

  An advertised list is taken **whole or not at all** — any malformed entry, a bad id
  (not `[A-Za-z0-9_-]{1,24}`), a label over 24 printable ASCII characters, more than 10
  tabs, or a list over 384 bytes drops the list, and the peer then shows its built-in one.
  The list is runtime-only (no flash writes: the companion re-sends it on every heartbeat)
  and is cleared when the companion deregisters.

### Fixes

- **Watchdog reboot on a large wall.** `GET /api/flap/modules` sent one chunk per
  module. Each chunk could block on a slow client for up to the 3 s socket timeout, so
  ~41 modules × 3 s exceeded the 120 s web-stall threshold — the supervisor logged
  `STALL: Web=0` and **rebooted the gateway**. It never fired below ~40 modules, which
  is why it hid for so long. The response is now coalesced into ~1400-byte chunks, feeds
  the watchdog on each flush, and aborts early if the client has gone away.

- **A changed MQTT broker now takes effect.** `POST /api/config/mqtt` saved the new
  host/port but never told PubSubClient about it, so the client kept dialling the
  **boot-time** broker and failed forever with `rc=-2` until a reboot. It now re-points
  the client and resets the failure counter.

- **TCP connect timeouts were never actually set.** Several call sites used
  `setTimeout()`, which on `NetworkClient` sets the *read* timeout and leaves the
  **connect** timeout at its 3 s default — the MQTT client and three web handlers all
  meant the latter. They now call `setConnectionTimeout()`.

- **The dashboard re-downloaded its whole page on every navigation.** `GET /` now sends
  an `ETag` and answers a matching `If-None-Match` with `304 Not Modified` (~53 KB
  saved per navigation); the favicon and logo are cached for a week. The dashboard also
  gates its periodic polls so they can't stack up on the one-connection web server.

### New

- **Tab advertisement (`POST /api/companion`).** The companion may now send `tabs` —
  the deep links its own UI offers — and the response always carries `gwTabs`, this
  firmware's. Each side then renders the other's real tabs instead of a list hard-coded
  on the far side, which is what made the Backup tab above a two-release problem.

  Both halves are optional and independent, so **every old/new pairing works**: an older
  companion advertises nothing and the dashboard falls back to its built-in companion
  tabs; an older gateway returns no `gwTabs` and the companion falls back to its own list
  (which still includes **Backup**, because a pre-3.4 gateway really does have that tab).

  An advertised list is taken **whole or not at all** — any malformed entry, a bad id
  (not `[A-Za-z0-9_-]{1,24}`), a label over 24 printable ASCII characters, more than 10
  tabs, or a list over 384 bytes drops the list, and the peer then shows its built-in one.
  The list is runtime-only (no flash writes: the companion re-sends it on every heartbeat)
  and is cleared when the companion deregisters.

---

## v3.2 — 2026-07-10

Adds a **Home All** button to the web UI. Drop-in upgrade from v3.1 — no API,
MQTT, or module-behaviour changes; the only change is in the dashboard.

### New

- **Home All button.** The Display tab (under the Live Display) and the
  Calibration tab (in the module picker) each gained a **Home All** button that
  homes every module at once — it broadcasts `m*h` via the existing
  `POST /api/flap/home` with `{"id":-1}`, so there's no new endpoint.

---

## v3.1 — 2026-07-09

Lets the **[Companion App](https://github.com/avandeputte/SplitFlapGatewayCompanion)**
store its settings in the gateway's flash, so a companion container becomes
stateless — destroy it, start another on any host, and it restores its
configuration from the gateway. Drop-in upgrade from v3.0: every existing
endpoint, MQTT topic and module behaviour is unchanged, and the additions are
purely a new endpoint pair plus one new config field.

### New

- **Companion settings blob store.** The gateway now offers a small, dumb blob
  store that the companion owns end to end:
  - `GET /api/companion/settings` → the stored `gzip(minified JSON)` body as
    `application/gzip`, or `404` when nothing is stored yet.
  - `PUT /api/companion/settings` → stores the gzipped body **verbatim**; replies
    `{"ok":true,"bytes":N}`.

  The firmware never parses the payload — the companion owns the schema and
  compresses/decompresses at its own end. Writes are **atomic**: the body streams
  to a temp file on the FATFS partition and is renamed over the live copy only
  once the last byte lands, so an interrupted upload cannot corrupt settings that
  were already good. The blob (`/compset.gz`) survives OTA firmware updates, is
  capped at 64 KB (real ones are 1–2 KB), and the companion debounces its writes,
  so this costs the flash almost nothing.

  Errors are `400` (empty or truncated body), `413` (too large), `503`
  (filesystem not mounted) and `507` (write failed) — in every one of them the
  previously stored blob is left untouched.

- **Firmware version in `GET /api/config`.** The response now carries
  `"version"` (e.g. `"3.1.0"`). This is how the companion decides whether a
  gateway is new enough to hold its settings; against a 3.0 gateway the field is
  absent and the companion quietly falls back to storing them locally.

### Notes

- The gzipped body is served as `application/gzip` and deliberately **without**
  `Content-Encoding: gzip` — those bytes are the payload, not a transfer encoding
  of it. Declaring the encoding would make HTTP clients transparently decompress
  the body, and the companion decompresses it itself.
- `OPTIONS` preflights now advertise `PUT` alongside `GET,POST`.
- The v3.0 `/api/companion` registration endpoint, previously undocumented, is now
  described in `openapi.yaml` along with the new pair.

---

## v3.0 — 2026-07-07

Adds **batch RS-485 send** and an automatic **Quiet-Time schedule**, plus a
cleaner dashboard and a more robust bus monitor. Drop-in upgrade from v2.1 — all
existing endpoints, MQTT topics, and module behaviour are unchanged; the
additions are purely new config + endpoints.

### New

- **Batch RS-485 send.** `POST /api/rs485/batch` accepts many frames in one
  request (`{"frames":[…],"step_ms":15}`), each normalized like `/api/rs485/send`,
  with an optional device-side `step_ms` pacing the cascade. A host can now draw
  a whole animated page in a single HTTP call instead of one request per module.
  Capped at 512 frames / 8 s of pacing; feeds the web watchdog during long
  batches.
- **Quiet-Time schedule.** Quiet Time can turn on/off automatically on a daily
  schedule. Configure it under **Settings → Quiet Time Schedule** (enable, a
  start/end time, and the days it applies). The schedule is evaluated once a
  second against the RTC and toggles Quiet Time as local time crosses the window
  (overnight windows supported). Transition-based, so a manual toggle within a
  window is respected until the next boundary. Persisted in NVS.
  - `GET`/`POST /api/quiet/schedule` → `{enabled,start,end,days}` (`days` is a
    bitmask, bit0=Sun … bit6=Sat).

### Web UI

- **Cleaner top bar.** The maintenance checkbox and the IP address were removed
  from the header, which now shows just the logo and version badge. Maintenance
  mode is still signalled by the yellow border and banner — and that banner now
  carries a one-click **Turn Off Maintenance** button. (The gateway's IP remains
  on the **Status** page.)

### Fixes

- **Valid JSON on the bus-monitor MQTT topics.** A frame containing a `"` or `\`
  could emit malformed JSON on the `<prefix>/rx` and `<prefix>/tx` monitor topics
  (those characters weren't escaped). They are now escaped; the MQTT and
  web-monitor encoders share one transcoder; and the MQTT buffer was enlarged so
  a full frame of accented / multi-byte glyphs is never truncated mid-message.

### Companion app

- **[SplitFlapGatewayCompanion](https://github.com/avandeputte/SplitFlapGatewayCompanion)
  is released.** A content engine — apps, playlists, schedules and triggers — that
  drives the display over this release's batch endpoint and registers itself with
  `POST /api/companion`, which makes a **Companion** tab appear on the gateway. It
  requires v3.0 or newer. See [Companion App](README.md#companion-app).

### Compatibility & upgrade notes

- No breaking changes: existing REST endpoints, MQTT topics, and backups from
  earlier versions are unchanged. Upgrade the gateway over-the-air as usual
  (Settings → firmware update), then confirm the version badge in the header
  reads **v3.0**.

## v2.1 — 2026-06-29

A bug-fix release that makes the **colour flaps** work correctly end to end and the **calibration tools honour a module's custom flap set**. It is a drop-in upgrade from v2.0 — all endpoints, MQTT topics, and module behaviour are unchanged.

### Fixes

- **Colour flaps are no longer turned into letters.** The seven colour flaps are addressed by the lowercase letters `r o y g b p w` (red, orange, yellow, green, blue, pink, white), but the gateway was normalising *all* lowercase ASCII to uppercase before sending — so a request for blue (`b`) went out as the letter `B`. Lowercase letters are still uppercased to match the default reel, **except** those seven colour codes, which now pass through verbatim. Ordinary text is unaffected (`hello` → `HELLO`); lowercase is now meaningful for colours (`b` → blue flap).
- **Calibration Wizard and Character Map now reflect a module's custom flap set.** Both were hardcoded to the default 64-flap reel, so a module on firmware v31+ with a custom character set or flap count was still calibrated against `A B C …`. They now read the module's live character set and flap count (via the combined `A` dump / `/api/flap/all`) and use them throughout — the map labels, the Wizard's per-flap glyph and progress, the whole-board walk, and the default per-flap step positions (spaced by the module's actual flap count, not a fixed 64).
- **Live Display renders colour flaps.** A flap currently showing a colour now appears as a colour swatch on the Live Display wall, matching the Character Map, instead of printing the bare colour letter.
- **Lowercase is visible on the Display tab.** The Send Text and Send Single Character inputs no longer force-uppercase what you type on screen, so you can enter and see the lowercase colour codes you are sending.
- **The web UI no longer serves a stale page after an update.** The embedded page is now sent with `Cache-Control: no-cache`, so a normal reload always loads the new UI after a firmware flash — previously the browser could keep serving the cached HTML/JS, making an update look like it had no effect.

### Compatibility & upgrade notes

- No API, MQTT, or wiring changes; backups are unaffected. The custom-flap-set calibration display requires module firmware **v31+** (older modules use the fixed 64-flap default reel, exactly as before).
- Upgrade the gateway over-the-air as usual (Settings → firmware update), then confirm the version badge in the header reads **v2.1**. Because of the caching fix, do **one** hard refresh (Cmd/Ctrl + Shift + R) after this upgrade; subsequent updates refresh on a normal reload.

## v2.0 — 2026-06-28

Adds gateway support for the **runtime-configurable flap set** introduced in **module firmware v31**: the active flap count (1–64) and the ordered character set are now set per module from the gateway, read back, and preserved across backup/restore. It is a drop-in upgrade — every existing endpoint, MQTT topic, and module behaviour is unchanged, and the new controls simply stay inert for modules on older firmware.

### Highlights

**Configurable flap set (requires module firmware v31+)**

Module firmware v31 made the physical flap count and the character order (which character lives at each flap index) configurable at runtime via a new `N` command, persisted in the module's EEPROM, instead of the previously fixed 64-flap built-in set. The gateway now drives that end to end:

- **Module Info dialog** — for a module on firmware **v31+**, shows the live **active flap count** and **character set** (read from the module's `A` dump) and provides an inline editor to change either or both. The flap count and the character set are **independent** — set one and leave the other untouched; leave a field blank to keep the module's current value. The Flap Set section is shown **only** for v31+ modules and is omitted entirely on older firmware.
- **Whole-panel broadcast** — target `id:-1` to push one flap set to every module on the bus in a single command (the calibrated map and other per-module state are untouched).
- **By serial number** — a flap set can also be addressed to a specific module's serial number.
- **Euro sign and accented characters (Windows-1252)** — the flap character set is no longer limited to ASCII. You can use the euro sign `€` (e.g. instead of `$`) and Western-European accented letters (`é à ü ö ä ñ ç ß …`) on the flaps. Characters are entered as normal UTF-8 in the web UI / JSON; the gateway transcodes them to the single-byte Windows-1252 form the RS-485 bus and module firmware use, and back to UTF-8 when reading the set or the live display. Each glyph is one flap; characters with no Windows-1252 representation (emoji, non-Latin scripts) are rejected. This applies to the configured flap set **and** to characters/text sent to the display. No firmware change is required (the module stores raw bytes).
- **Backup & restore round-trip** — a backup now also captures each module's configured flap count and character set (from the v31+ `A` dump), and a restore re-applies them, so a full backup/restore preserves a custom flap set. Modules on older firmware are unaffected (the tail is simply absent).

### REST / MQTT additions

Additive — existing endpoints and topics are unchanged:

| Interface | Endpoint / Topic | Description |
|---|---|---|
| `POST` | `/api/flap/flapconfig` | Configure flap count and/or character set by `id` (`id:-1` broadcasts) or `sn` (firmware v31+) |
| MQTT | `<prefix>/flap/flapconfig` | Same, e.g. `{"id":5,"flapCount":40,"charSet":" ABC…"}` |

`/api/flap/all` now also returns `flapCount` and `flapChars` (`-99` / `""` for pre-v31 firmware), and `/api/flap/restorebysn` accepts an optional `flapCount`/`charSet` to restore the flap set. The combined `A` reply parser reads the new `:<flapCount>:<flapChars>` tail (and, thanks to the forward-compatible parser added in v1.8, older gateways already ignore it safely).

### Compatibility & upgrade notes

- **The configurable flap set requires module firmware v31 or newer.** The Info dialog hides the Flap Set section entirely for modules below v31 (they use the fixed 64-flap default set); the new endpoint/topic still accept requests but an older module ignores the unknown `N` command. Every other feature works with any module firmware.
- No breaking changes: existing endpoints, MQTT topics, and backup files from earlier versions still work (an old backup simply has no flap-set tail to restore).
- Upgrade the gateway over-the-air as usual (Settings → firmware update), then confirm the version badge in the header reads **v2.0**.

## v1.9 — 2026-06-17

A polish and reliability release: a fix for present-but-quiet modules occasionally dropping off the known-module list, a refreshed browser presence (favicon and header logo), and clearer module action icons. It is a drop-in upgrade from v1.8 — all endpoints, MQTT topics, and module behaviour are unchanged.

### Fixes

- **Stale-module purge no longer drops live modules.** Modules unseen past the 6 h staleness window are *probed* before being purged, but the gateway was firing those version-query probes back-to-back. Because a module answers a bare version query **synchronously and instantly**, on the half-duplex bus each reply collided with the next probe and was lost — so present-but-quiet modules (e.g. on an idle display left on one message, where they all go stale together) were dropped despite being "probed." Probes are now **spaced out** and sent in **bounded batches**, so every reply is received and the module is kept. A module is purged only if it genuinely stays silent after a clean probe.

### Web UI

- **Browser icon (favicon).** A split-flap-themed SVG favicon is now served at `/favicon.svg` and shown in the browser tab and bookmarks.
- **Header logo.** The "Split-Flap Gateway" title is now a split-flap *board* wordmark — each letter on its own flap tile, with the seam and pivots of the favicon — served at `/logo.svg` in place of the plain text. It scales down on narrow screens.
- **Clearer module action icons.** The diagnostics (stethoscope) and delete (trash) buttons were color emoji that ignored the UI's colours and rendered low-contrast on the dark theme. They are now monochrome SVG icons that inherit the button colour, so the diagnostics icon is crisp and the delete icon correctly renders **red**, matching its intended destructive-action styling.

### Project

- **In-file license header.** The firmware source now carries the project's Creative Commons Attribution-NonCommercial-ShareAlike 4.0 (CC BY-NC-SA 4.0) notice in-file, with credit to **Adam G Makes** for the split-flap module hardware and the initial protocol.

### Compatibility & upgrade notes

- No API, MQTT, or wiring changes. Upgrade the gateway over-the-air as usual (Settings → firmware update) and confirm the header badge now reads **v1.9**.

## v1.8 — 2026-06-17

This release adds **module hardware self-diagnostics** and a **whole-board calibration** mode, along with the supporting REST API, web UI, and documentation. It is a drop-in upgrade from v1.7 — all existing endpoints, MQTT topics, and module behaviour are unchanged.

### Highlights

**Module self-diagnostics (requires module firmware v26+)**

A 🩺 diagnostics icon now appears on every provisioned module whose firmware is **v26 or newer**. Clicking it runs three built-in self-tests in order and opens a results modal with plain-language interpretation:

- **Stats snapshot (`Q`)** — instant, no motor movement. Reports the last reset cause (decoded from the RSTFR bits into power-on / brown-out / external / watchdog / software), the boot counter, supply voltage, an EEPROM write-verify result, and the current flap index. It highlights a sagging supply, a failed EEPROM verify, or a brown-out / watchdog reset. The supply-voltage check is **rail-aware**, so a healthy 3.3 V module is not mistaken for a low 5 V rail.
- **Hall sensor self-test (`T`)** — spins the reel ~2 revolutions to check the home sensor and reports **OK** or one of **stuck-active**, **stuck-inactive**, **multiple active regions**, or **inverted polarity**, with the rising/falling home-edge counts.
- **Mechanical self-test (`M`)** — spins the motor several revolutions and reports **OK**, **inconsistent** (revolutions varied by more than 5 %, indicating intermittent missed steps from drag, a weak supply, or a failing driver), or **no motion**. It also reports the per-revolution step counts, average magnet width, and motion-gate detail that distinguish a stalled motor from a dead sensor. On **firmware v29+** the rotation count is selectable (**5–20**, default 5) — more rotations catch intermittent faults a short run misses. The Hall and mechanical tests are motor-driven, so they run as asynchronous jobs the UI polls; the snapshot shows immediately.

**Whole-board calibration**

A new **Calibrate Whole Board** mode steps every module through each flap at the same time, so you can walk the entire wall one flap at a time and fix any module that is off using the familiar per-character nudge dialog — no need to calibrate modules one by one. The single-module and whole-board flows now live in one consolidated **Calibration** section. Maintenance mode is left exactly as it was found when you finish.

### REST API additions

Three new endpoints (additive — existing endpoints are unchanged):

| Method | Endpoint | Description |
|---|---|---|
| `POST` | `/api/flap/diag` | Returns the stats snapshot `q` inline and starts the Hall sensor test |
| `POST` | `/api/flap/diag/mech` | Starts the mechanical self-test after the Hall test; optional `revs` 5–20 (firmware v29+, default 5) |
| `GET` | `/api/flap/diag/status` | Polls the active motor test (`kind` hall/mech): `idle` / `pending` / `done` / `timeout` |

All are documented in `openapi.yaml` and the README's REST API section.

### Fixes

- **Rail-aware supply-voltage check** — a healthy 3.3 V reading is no longer reported as a low supply. The threshold now adapts to the rail (warn below ~3.0 V on a 3.3 V module, below ~4.5 V on a 5 V module).
- **Build fix** — a malformed configuration line (two `#define` directives merged onto one line, leaving `MODULE_PROBE_GRACE_MS` swallowed by a comment) broke compilation; the directives are now on separate lines.
- **Diagnostics polling robustness** — the results poller now keeps a single request in flight and fires exactly once, so a test result can no longer be clobbered by a late "idle" poll (which previously showed "test did not complete" even when the module had returned valid data).
- **Forward-compatible `A` parser** — the all-fields reply parser ignores any field a future module firmware appends after the calibration map, instead of folding it into the map.

### Compatibility & upgrade notes

- **Self-diagnostics requires module firmware v26 or newer** (the 🩺 icon only appears on those modules); the **selectable rotation count needs v29+** — on v26–v28 the mechanical test runs the fixed default of 5 rotations. Every other feature works with any module firmware.
- The new API endpoints are backward-compatible; no client changes are required.
- Upgrade the gateway over-the-air as usual (Settings → firmware update), then confirm the version badge in the header.

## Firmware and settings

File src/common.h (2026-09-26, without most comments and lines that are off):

#define SFGW_COMMON_H
#include <Arduino.h>
#include <WiFi.h>
#include <WebServer.h>
#include <Preferences.h>
#include <PubSubClient.h>
#include <ArduinoJson.h>
#include <HardwareSerial.h>
#include <Wire.h>
#include <time.h>
#include <ArduinoOTA.h>
#include <Update.h>
#include <FFat.h>
#include <ESPmDNS.h>
#include <esp_mac.h>
static inline uint32_t boardId24() {          // 6 hex digits -- hostname suffix
  uint8_t m[6] = {0};
  esp_efuse_mac_get_default(m);
  return ((uint32_t)m[3] << 16) | ((uint32_t)m[4] << 8) | (uint32_t)m[5];
}
static inline uint32_t boardId32() {          // 8 hex digits -- MQTT client id, HA node id
  uint8_t m[6] = {0};
  esp_efuse_mac_get_default(m);
  return ((uint32_t)m[2] << 24) | ((uint32_t)m[3] << 16)
       | ((uint32_t)m[4] << 8)  | (uint32_t)m[5];
}
#define RS485_TX_PIN   17
#define RS485_RX_PIN   18
#define RS485_EN_PIN   21          // DE/RE direction control (high = transmit)
#define I2C_SDA_PIN       39
#define I2C_SCL_PIN       38
#define PCF85063_ADDR     0x51
#define PCF85063_SEC_REG  0x04
#define PCF85063_CTRL1    0x00
#define RTC_YEAR_OFFSET   2000     // PCF85063 reg 6 is 0-99 = 2000-2099
#define FW_VERSION           "3.13.1"         // gateway firmware version (UI + boot log)
#define PRODUCT_NAME         "Split-Flap Gateway"
#define API_VERSION          "3.1.0"
#define DEFAULT_AP_SSID      "Split-Flap-GW"  // SoftAP SSID when no WiFi configured
#define DEFAULT_AP_PASS      "12345678"       // SoftAP password (>= 8 chars)
#define DEFAULT_BAUD         9600UL           // RS-485 bus baud rate
#define DEFAULT_MQTT_PORT    1883
#define DEFAULT_MQTT_PREFIX  "splitflap"
#define DEFAULT_NTP_SERVER   "pool.ntp.org"   // overridable via Settings
#define NTP_TIMEOUT_MS       8000UL
#define TX_BUS_GUARD_MS      12
#define TX_BUS_WAIT_CAP_MS   400
#define MSG_RING_SIZE        64    // monitor ring: number of frames retained
#define MSG_MAX_BYTES        256   // monitor ring: bytes stored per frame
#define TX_MAX_BYTES         768   // max bytes rs485Send will transmit in one frame
#define MQTT_BUF_SIZE        1024  // MQTT packet buffer + queue slot: holds a full
#define MQTT_Q_SIZE          32    // outbound MQTT publish queue depth
#define SF_MAX_FLAPS         64
#define STATUS_INTERVAL_MS      60000UL   // MQTT status publish cadence (1/min)
#define MODULE_STALE_SECS       86400UL   // 24h: a module not heard from in this long is RE-QUERIED (a bare version query) so its record stays current. It is never dropped for being quiet (v3.12): the registry is permanent -- only Identify All, De-provision, or a corrupt record removes an entry. Modules only speak when addressed, so a long-lived static message is not a sign of absence.
#define MODULE_REPROBE_BACKOFF_MS 3600000UL // after MODULE_PROBE_MAX_TRIES unanswered re-queries, leave the module alone for this long before asking again (it stays in the registry throughout)
#define MODULE_PROBE_GRACE_MS   3000UL    // wait this long for a stale module's version reply before the next probe attempt
#define MODULE_PROBE_SPACING_MS 150UL     // gap between consecutive stale probes: a module answers a bare 'v' INSTANTLY, so back-to-back queries make each reply collide with the next probe -- space them so every reply is received (and clears the probe) before the next query goes out
#define MODULE_PROBE_BATCH      8         // max stale modules probed per prune cycle; the rest are probed on later cycles (bounds the net task's spaced-probe burst)
#define MODULE_PROBE_MAX_TRIES  4         // unanswered re-queries (one per ~1 min cycle) before backing off for MODULE_REPROBE_BACKOFF_MS. A single reply is easily lost to a bus collision while the host is streaming display frames, so one probe is not proof of absence.
#define MODULE_POSTPROV_VER_MS  4000UL    // delay after a provisioning ack before the first version query. A freshly-provisioned module writes its new ID to EEPROM and then runs a staggered startup (~150ms x new-ID), so it can be unresponsive for several seconds; wait well past that before the first query.
#define MODULE_VER_RETRY_MS     2500UL    // gap between post-provision version-query retries
#define MODULE_VER_MAX_TRIES    6         // give up after this many version-query attempts (covers ~4s + 5x2.5s ~= 16s)
#define COMPANION_SAVE_DEBOUNCE_MS 120000UL   // companion URL: persist once it settles
#define MODULE_SAVE_DEBOUNCE_MS 5000UL    // coalesce NVS writes
#define MAX_MODULES         255   // module IDs 0-254
#define DUP_ID_REJECT_WINDOW_MS 60000UL   // rolling window for counting corrupt version/all replies
#define DUP_ID_REJECT_THRESHOLD 3         // this many within the window -> flag a possible duplicate ID
#define FLAPSET_QUERY_MS      2000UL   // at most one 'A' flap-set query per this interval
#define FLAPSET_RETRY_MS     20000UL   // a module that didn't answer: wait this long, try again
#define FLAPSET_MAX_TRIES         3    // then give up; it reports as "unknown", not as a lie
#define FLAPSET_FW_MIN           31    // the firmware that first reports its set at all
#define FLAPSET_DEFAULT " ABCDEFGHIJKLMNOPQRSTUVWXYZ0123456789!@#$&()-+=;q:%'.,/?*roygbpw"
#define FLAP_COLOUR_CODES  "roygbpw"
#define MODULES_FILE     "/modules.dat"
#define MODULES_MAGIC    0x53464733UL   // "SFG3" (bumped: PersistedModule gained the flap set)
#define COMPANION_FILE       "/compset.gz"
#define COMPANION_TMP        "/compset.tmp"
#define COMPANION_MAX_BYTES  (64UL * 1024UL)
#define COMPANION_TABS_MAX     384
#define COMPANION_TABS_MAX_N   10    // max tabs accepted from a companion
#define COMPANION_TAB_ID_MAX   24    // max chars of one tab's id (the URL hash)
#define COMPANION_TAB_LBL_MAX  24    // max chars of one tab's label
#define DEFAULT_STEP_MS           15
#define STEP_MS_MAX               100
#define RESTORE_FILE              "/restore.bak"
#define RESTORE_TMP               "/restore.tmp"
#define RESTORE_MAX_BYTES         (256UL * 1024UL)
#define RESTORE_DEFAULT_DELAY_S   10       // seconds after boot before the replay starts
#define RESTORE_MAX_DELAY_S       600
#define RESTORE_STEP_MS           500UL    // silence after a provisioning frame
#define RESTORE_MXW_SETTLE_MS     1000UL   // after mXW: the module erases the map and writes the flap set
#define RESTORE_ENTRY_GAP_MS      60UL     // between m<id>w entries (~12 ms on the wire + ~7 ms EEPROM)
#define RESTORE_SETTLE_MS         2500UL   // from a module's last write to its first read-back
#define RESTORE_VERIFY_TIMEOUT_MS 1500UL   // wait for a read-back ('A' is ~200 bytes at 9600 baud)
#define RESTORE_VERIFY_TRIES      2        // read-back attempts per module per round
#define RESTORE_REPAIR_ROUNDS     1        // a mismatch/silent module is re-written and re-read this many times
#define DBG(...) do { if (gSerialDebug) printf(__VA_ARGS__); } while(0)
extern volatile bool gSerialDebug;
extern volatile bool gMaintenanceMode;
extern volatile bool gQuietTime;
extern char gCompanionStatus[80];          // v3.0: companion running-status
extern volatile unsigned long gCompanionSeenMs;
extern char gCompanionTabs[COMPANION_TABS_MAX];
extern volatile bool          gCompanionUrlDirty;
extern volatile unsigned long gCompanionUrlDirtyMs;  // millis() of last companion post
extern volatile bool gDisplayDirty;
extern volatile bool gOtaInProgress;
extern char gWallChars[256];
extern bool gApActive;
extern SemaphoreHandle_t timeMutex;
extern StaticSemaphore_t timeMutexBuf;
extern volatile unsigned long wdgRS485Ms;
extern volatile unsigned long gLastRxMs;
extern volatile unsigned long wdgNetMs;
extern volatile unsigned long wdgWebMs;
extern TaskHandle_t hTaskRTC, hTaskRS485, hTaskOTA, hTaskWeb, hTaskNet;
extern bool ntpSynced;
extern unsigned long staDownSince;

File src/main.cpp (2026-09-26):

#include "gateway.h"
#include <esp_ota_ops.h>   // esp_ota_get_running_partition(): which slot are we actually running?

// After this many crash/watchdog reboots in a row, the boot logic reformats FATFS -- a corrupt
// filesystem is the one thing that can crash a flash write and boot-loop the board. See setup().
#define PANIC_REFORMAT_THRESHOLD 3
// Consecutive crash/watchdog reboots, kept in RTC memory: it survives a reboot but is garbage on
// a cold power-up. Written in setup(), cleared in loop() once the board has run healthy for 60s.
RTC_NOINIT_ATTR static uint32_t sfPanicBoots;



// main.cpp -- boot sequence and supervisor.
// setup() brings the system up in dependency order (mutexes and PSRAM buffers,
// config, RTC + module registry, RS-485, WiFi, servers, then the tasks).
// loop() is the watchdog supervisor: it logs periodic telemetry and reboots if
// a task stalls or the heap runs critically low. The protocol/REST/MQTT
// reference lives in the comment block at the bottom of this file.
/* ----------------------------------------------------------
   setup / loop
---------------------------------------------------------- */
void setup() {
  // 1. Mutexes first - must exist before any task touches shared data
  msgMutex   = xSemaphoreCreateMutexStatic(&msgMutexBuf);
  sfMutex    = xSemaphoreCreateMutexStatic(&sfMutexBuf);
  timeMutex  = xSemaphoreCreateMutexStatic(&timeMutexBuf);
  mqttQMutex = xSemaphoreCreateMutexStatic(&mqttQMutexBuf);
  txMutex    = xSemaphoreCreateMutexStatic(&txMutexBuf);
  txQMutex   = xSemaphoreCreateMutexStatic(&txQMutexBuf);
  psramAllocInit();   // allocate large buffers (ring + MQTT queue + registry) in PSRAM

  // Debug output via native USB CDC (USB CDC On Boot: Enabled).
  // Port appears as /dev/cu.usbmodem* on macOS, COMx on Windows, /dev/ttyACM0 on Linux.
  // Connect at 115200 baud.
  Serial.begin(115200);
  { unsigned long t = millis(); while (!Serial && millis() - t < 3000) delay(10); }
  delay(200);
  printf("\n[Boot] Split-Flap Gateway v%s\n", FW_VERSION);
  // Which app slot is actually running, and when it was built. A serial reflash writes ota_0 and
  // resets otadata, but an OTA leaves the selector on the other slot -- so this is the first thing
  // to check when a board seems to be running firmware you did not just flash.
  { const esp_partition_t* rp = esp_ota_get_running_partition();
    printf("[Boot] running slot=%s, built %s %s\n", rp ? rp->label : "?", __DATE__, __TIME__); }
  // Reset reason + chip/heap snapshot -- the first thing to check after an
  // unexpected reboot. PANIC/INT_WDT/TASK_WDT point at firmware faults;
  // BROWNOUT points at power. Pair this with the last [WDG] line before the gap.
  bool fatfsRecover = false;   // set by the panic-recovery check inside the block below
  {
    esp_reset_reason_t rr = esp_reset_reason();
    const char* rs = "OTHER";
    switch (rr) {
      case ESP_RST_POWERON:  rs = "POWERON";  break;
      case ESP_RST_SW:       rs = "SW";       break;
      case ESP_RST_PANIC:    rs = "PANIC";    break;
      case ESP_RST_INT_WDT:  rs = "INT_WDT";  break;
      case ESP_RST_TASK_WDT: rs = "TASK_WDT"; break;
      case ESP_RST_WDT:      rs = "WDT";      break;
      case ESP_RST_BROWNOUT: rs = "BROWNOUT"; break;
      case ESP_RST_DEEPSLEEP:rs = "DEEPSLEEP";break;
      default: break;
    }
    printf("[Boot] reset=%s heap=%u psram=%u flash=%uKB sdk=%s\n",
           rs, ESP.getFreeHeap(), ESP.getPsramSize(),
           ESP.getFlashChipSize()/1024, ESP.getSdkVersion());

    // Panic-recovery safeguard. sfPanicBoots lives in RTC memory: it survives a reboot -- even a
    // crash reboot -- and is only garbage on a cold power-up, which POWERON zeroes below. A
    // corrupted FATFS can crash a flash write and boot-loop the board (which is exactly what
    // happened once). After PANIC_REFORMAT_THRESHOLD crash/watchdog reboots IN A ROW -- each
    // before the board runs healthy for 60s, at which point loop() clears the count -- reformat
    // FATFS on this boot to break the loop: one self-healing reboot instead of a brick.
    const bool crashReset = (rr == ESP_RST_PANIC || rr == ESP_RST_INT_WDT ||
                             rr == ESP_RST_TASK_WDT || rr == ESP_RST_WDT);
    if (rr == ESP_RST_POWERON || rr == ESP_RST_BROWNOUT) sfPanicBoots = 0;   // cold boot: init RTC
    else if (crashReset)                                  sfPanicBoots++;
    else                                                  sfPanicBoots = 0;   // clean SW reset/OTA
    if (sfPanicBoots >= PANIC_REFORMAT_THRESHOLD) {
      printf("[RECOVERY] %u crash reboots in a row -- reformatting FATFS to break the loop\n",
             (unsigned)sfPanicBoots);
      sfPanicBoots = 0;
      fatfsRecover = true;
    }
  }

  // 2. Load config and init module registry
  cfgSetDefaults();
  loadConfig();
  memset(sfModules, 0, sizeof(SFModule) * MAX_MODULES);
  for (int i = 0; i < MAX_MODULES; i++) sfModules[i].id = 255;
  sfModuleCount = 0;

  // 3. I2C + RTC (must be before WiFi so timestamps work from boot)
  rtcHwInit();
  rtcRead(); // load whatever time is stored in RTC chip

  // Restore sticky module list from the FATFS file (prunes entries older
  // than 6h). Mount the filesystem first; done after rtcRead() so
  // rtcEpochNow() can evaluate staleness.
  sfFsInit(fatfsRecover);
  sfModulesLoad();

  // 4. RS485
  rs485Begin();

  // 5. WiFi - MUST be initialised here on the main Arduino task.
  // The SoftAP is a FALLBACK only: start in station mode and connect to the
  // configured network. If no network is configured, bring the fallback AP up
  // immediately so the gateway is reachable for first-time setup. If a network
  // is configured but the station fails to connect, the network task brings the
  // fallback AP up after a grace period (and drops it again once the station
  // connects), so a working WiFi link never leaves the AP running.
  WiFi.mode(WIFI_STA);
  WiFi.setSleep(true);
  if (strlen(cfg.wifiSSID)) {
    WiFi.begin(cfg.wifiSSID, cfg.wifiPass);
    staDownSince = millis();   // start the fallback grace timer from boot
    printf("[WiFi] STA connecting to %s...\n", cfg.wifiSSID);
  } else {
    wifiSetApActive(true);   // no credentials -> fallback AP for setup
    printf("[WiFi] No network configured -- fallback AP only\n");
  }

  // 6. Web server
  otaInit();
  mqttInit();
  webInit();

  // 7. Restore-on-boot (v3.12). If enabled and a usable backup is stored, this locks the
  // bus NOW -- before any task exists, so nothing (the quiet-time schedule included) can
  // touch the bus first -- and schedules the replay for cfg.restoreDelaySec after boot, so
  // the modules have finished their own power-up homing. The lock always releases: see
  // restore.cpp. (Moved ahead of the tasks in v3.13.1: it used to follow them, and the
  // first schedule tick could assert Quiet Time in the gap.)
  restoreInit();

  // 8. Spawn tasks after WiFi stack is ready
  xTaskCreatePinnedToCore(taskRTC,     "RTC",     2048, NULL, 2, &hTaskRTC,   0);
  xTaskCreatePinnedToCore(taskRS485,   "RS485",   6144, NULL, 3, &hTaskRS485, 0);
  xTaskCreatePinnedToCore(taskOTA,     "OTA",     4096, NULL, 1, &hTaskOTA,   1);
  xTaskCreatePinnedToCore(taskWeb,     "Web",     8192, NULL, 2, &hTaskWeb,   0);
  xTaskCreatePinnedToCore(taskNetwork, "Network", 6144, NULL, 1, &hTaskNet,   1);

  printf("[Boot] Ready\n");
}

void loop() {
  static unsigned long lastWdgCheck = 0;
  unsigned long now = millis();
  // Panic-recovery: once we have run healthy for a minute, this boot plainly was not a crash
  // loop, so clear the RTC crash counter -- only RAPID consecutive crashes (each before 60s)
  // accumulate toward the FATFS reformat in setup().
  static bool panicCounterCleared = false;
  if (!panicCounterCleared && now > 60000UL) { sfPanicBoots = 0; panicCounterCleared = true; }
  if (now - lastWdgCheck >= 30000UL) {
    lastWdgCheck = now;
    // Rich periodic telemetry for troubleshooting. Heap + min-ever heap +
    // largest free block (fragmentation: a big gap between freeHeap and
    // maxAlloc signals fragmentation, a common pre-crash signature). Per-task
    // stack high-water marks catch the canary-overflow class before it fires.
    // rx/tx/parse-reject counters surface bus health and corruption rates.
    unsigned freeHeap = ESP.getFreeHeap();
    unsigned minHeap  = ESP.getMinFreeHeap();
    unsigned maxBlk   = ESP.getMaxAllocHeap();
    unsigned s485 = hTaskRS485 ? uxTaskGetStackHighWaterMark(hTaskRS485) : 0;
    unsigned sWeb = hTaskWeb   ? uxTaskGetStackHighWaterMark(hTaskWeb)   : 0;
    unsigned sNet = hTaskNet   ? uxTaskGetStackHighWaterMark(hTaskNet)   : 0;
    unsigned sOta = hTaskOTA   ? uxTaskGetStackHighWaterMark(hTaskOTA)   : 0;
    unsigned sRtc = hTaskRTC   ? uxTaskGetStackHighWaterMark(hTaskRTC)   : 0;
    printf("[WDG] up=%lus heap=%u min=%u maxblk=%u frag=%u%% "
           "stk(485/web/net/ota/rtc)=%u/%u/%u/%u/%u "
           "rx=%lu tx=%lu rej=%lu wifi=%d ap=%d rssi=%d mqtt=%d mods=%d\n",
           now/1000, freeHeap, minHeap, maxBlk,
           freeHeap ? (unsigned)(100 - (maxBlk * 100UL / freeHeap)) : 0,
           s485, sWeb, sNet, sOta, sRtc,
           rxCount, txCount, sfParseRejects,
           (int)(WiFi.status()==WL_CONNECTED),
           (int)gApActive,
           (WiFi.status()==WL_CONNECTED) ? (int)WiFi.RSSI() : 0,
           (int)mqtt.connected(), sfModuleCount);

    // NEVER reboot the board while a web-OTA upload is in flight -- neither for a stall nor for
    // low heap. A firmware upload DELIBERATELY drives internal heap to the floor: a 1.45 MB image
    // streams in faster than flash can absorb it, so WiFi/lwIP receive buffers pile up and
    // min-free-heap has been seen at a few hundred bytes near the end. It also parks taskWeb
    // inside handleClient() for the whole transfer. Either reboot below would then reset the
    // board MID-FLASH, onto the old image -- exactly the "web OTA reaches ~98%, crashes, and comes
    // back on the previous firmware" symptom. If heap genuinely runs out, Update.write() fails and
    // handleOTAUpload aborts cleanly; a watchdog reboot only guarantees the failure. The upload
    // finishes in tens of seconds and, on success, reboots itself.
    const bool otaBusy = gOtaInProgress;

    // Boot grace period: skip stall detection for the first 60s. The first
    // boot after flashing formats the FATFS partition (a long blocking flash
    // operation), and WiFi/MQTT bring-up can briefly skew task scheduling.
    // Rebooting during this window would be a false positive.
    if (now < 60000UL || otaBusy) {
      // still arm the low-heap emergency check below, but skip stall logic
    } else {
      // Detect stalled tasks. A heartbeat in the future (wdg > now) can only
      // come from a transient timing skew during boot -- treat it as healthy
      // rather than letting the unsigned subtraction underflow to a huge value.
      bool ok485 = (wdgRS485Ms == 0 || wdgRS485Ms > now || now - wdgRS485Ms < 30000UL);
      bool okWeb  = (wdgWebMs  == 0 || wdgWebMs  > now || now - wdgWebMs  < 120000UL);
      bool okNet  = (wdgNetMs  == 0 || wdgNetMs  > now || now - wdgNetMs  < 30000UL);
      if (!ok485 || !okWeb || !okNet) {
        printf("[WDG] STALL: RS485=%d Web=%d Net=%d (age485=%lus ageWeb=%lus ageNet=%lus heap=%u) -- rebooting\n",
                      ok485, okWeb, okNet,
                      wdgRS485Ms ? (now - wdgRS485Ms)/1000 : 0,
                      wdgWebMs   ? (now - wdgWebMs)/1000   : 0,
                      wdgNetMs   ? (now - wdgNetMs)/1000   : 0,
                      ESP.getFreeHeap());
        delay(200);
        ESP.restart();
      }
    }
    // Emergency reboot if heap falls critically low (< 20KB) -- but NOT during an OTA upload,
    // which drives heap this low ON PURPOSE (see above). Rebooting here would abort the flash.
    if (!otaBusy && ESP.getFreeHeap() < 20000) {
      printf("[WDG] CRITICAL: heap=%u -- rebooting\n", ESP.getFreeHeap());
      delay(200);
      ESP.restart();
    }
  }
  vTaskDelay(pdMS_TO_TICKS(1000));
}

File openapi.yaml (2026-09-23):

openapi: 3.1.0
info:
  title: Split-Flap Gateway API
  version: "3.5"
  description: |
    REST API for the ESP32-S3 Split-Flap Gateway firmware (firmware v3.5).

    **Base URL:** `http://<gateway-ip>` — replace with the gateway's IP
    (shown on the Status page), or use `http://192.168.4.1` when connected to
    the AP fallback network.

    All `POST` endpoints accept and return `application/json`.
    All endpoints include `Access-Control-Allow-Origin: *`.

servers:
  - url: http://192.168.4.1
    description: AP fallback (default)
  - url: http://{ip}
    description: Station IP (after WiFi connect)
    variables:
      ip:
        default: "192.168.1.100"
        description: Gateway IP address

tags:
  - name: Bus
    description: Raw RS-485 bus access
  - name: Modules
    description: Split-flap module display control
  - name: Advanced
    description: Low-level module configuration commands
  - name: Provision
    description: Module provisioning and identity management
  - name: Status
    description: System status and diagnostics
  - name: Config
    description: Persistent configuration
  - name: Companion
    description: Companion-app registration and its settings blob store
  - name: Restore
    description: Restore-on-boot — a stored calibration backup replayed to every module (v3.12)
  - name: UI
    description: The dashboard itself (translation dictionaries)
  - name: OTA
    description: Over-the-air firmware update

paths:

  # ── RS-485 Bus ──────────────────────────────────────────────────

  /api/rs485/messages:
    get:
      tags: [Bus]
      summary: Drain buffered bus frames
      description: Returns all frames since the last call (up to 64). Each call drains the buffer.
      responses:
        "200":
          description: Array of bus frames (may be empty)
          content:
            application/json:
              schema:
                type: array
                items:
                  $ref: "#/components/schemas/BusFrame"

  /api/rs485/send:
    post:
      tags: [Bus]
      summary: Send a raw ASCII frame to the bus
      requestBody:
        required: true
        content:
          application/json:
            schema:
              type: object
              required: [data]
              properties:
                data:
                  type: string
                  description: >
                    ASCII frame to transmit. A trailing newline is optional — the
                    gateway normalizes framing (adds/strips the terminator and trims
                    any bytes past a complete known command) unless `raw` is true.
                raw:
                  type: boolean
                  default: false
                  description: >
                    When true, the bytes in `data` are sent verbatim with no
                    sanitization or terminator changes (debugging escape hatch).
            examples:
              home_all:
                value: { data: "m*h" }
              version_all:
                value: { data: "m*v" }
              show_char:
                value: { data: "m5-A" }
              raw_verbatim:
                value: { data: "m4vDSassa", raw: true }
      responses:
        "200":
          $ref: "#/components/responses/Ok"
        "400":
          $ref: "#/components/responses/BadRequest"

  /api/rs485/batch:
    post:
      tags: [Bus]
      summary: Send many raw frames in one request (v3.0)
      description: |
        Sends each frame in `frames` to the bus in order, normalized like
        `/api/rs485/send`. An optional `step_ms` paces the cascade device-side.
        Lets a host draw a whole animated page in one HTTP call instead of one
        request per module. Capped at 512 frames per request.

        **v3.4 — pacing is queued, not blocking.** A paced frame is stamped with a
        due time and handed to the bus task, which sends it when due; the handler
        no longer sleeps between frames. So the call **returns immediately** and
        `200` means the frames were **accepted**, not that they are on the wire —
        `sent` counts frames accepted. (Before 3.4 the handler blocked for the whole
        cascade, freezing the single-connection web server for up to 8 s; that 8 s
        total-pacing cap is gone with it.)
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

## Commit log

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2026-06-30 Fix calibration and color bugs
    [common.h, web.cpp]
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2026-07-12 Dashboard: adopt Home Assistant's design language — v3.2.1
    The project's UIs now share one look — Home Assistant's, matching the companion. An
    override block appended to the dashboard's stylesheet re-points the palette tokens and
    restyles the chrome (header, nav, cards, buttons, inputs); light and dark follow the
    browser/OS via prefers-color-scheme. The Live Display cells keep their hardcoded darks —
    they depict the physical flaps. UI-only; no API or behaviour changes.
2026-07-12 v3.4 — companion tab advertisement, backup into Settings, non-blocking batch pacing
    Engine:
    - /api/rs485/batch no longer paces with delay() on taskWeb. Frames are stamped
    with a due time and drained by taskRS485, so the single-connection web server
    stays responsive. 200 now means "accepted", not "transmitted"; the 8 s pacing
    budget is replaced by a 127-frame queue.
    - Companion URL is persisted on a 120 s debounce. Two companions heartbeating at
    one gateway flipped the value and caused an NVS write every ~30 s, forever.
    Fixes:
    - Watchdog reboot on walls >~40 modules: /api/flap/modules sent one chunk per
    module, so 41 x 3 s socket timeout crossed the 120 s web-stall threshold.
    R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
    [common.h, main.cpp, openapi.yaml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]
2026-07-12 Theme: reach the components that hardcode colours — v3.4.1
    Re-pointing the :root tokens turned most of the dashboard to the Home Assistant palette,
    but .mod (module cards), .stat (status tiles) and .logrow (bus monitor) hardcode #0d1b2a
    rather than reading a token, so they stayed navy against the new grey. Caught by rendering
    the real dashboard. They now read var(--card)/var(--acc).
    .wall/.flap still hardcode their darks on purpose — they draw the flap wall and should
    look like the physical modules, exactly as the companion's board does.
2026-07-13 Finish the Home Assistant re-skin: fix invisible text and stranded dark panels
    The re-skin re-points the palette tokens in :root, which only reaches components
    that READ a token. Everything that hardcoded the old dark palette, or that relied
    on --acc being a solid navy, was left behind -- several of them unreadable.
    Invisible in the light theme (now fixed):
    - button{color:#fff} is inherited, so any button overriding only the BACKGROUND
    kept white text. --acc went from solid navy to 12% black, so every .sec button
    (Refresh, Identify All, Home All, Re-read EEPROM), the plain nudge buttons,
    Tune's GOTO and the wizard's Back rendered white-on-#e0e0e0: 1.3:1.
    Secondary buttons now take c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
2026-07-13 v3.5 — multi-lingual dashboard, and fix the v3.4 re-skin's invisible controls
    ## Multi-lingual UI (13 languages)
    English plus en-GB, en-AU, fr, de, es, it, pt, pt-BR, nl, da, sv, nb, fi -- the
    languages whose text the flap modules could actually display (Windows-1252), so
    the dashboard and the wall speak the same set.
    Language follows the BROWSER, like the light/dark theme already does. In order:
    ?lang= in the URL (so the companion can request one for an embedded view without
    touching the user's setting -- deliberately not persisted) > a Settings override
    (localStorage) > navigator.languages > English. The gateway stores NO language
    state: no config field, no NVS write, no API.
    Every la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
    [common.h, openapi.yaml, web.cpp]
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2026-07-13 v3.6.1 — every gateway gets its own MQTT identity
    The MQTT client id and the Home Assistant device id were identical on every board:
    board A MAC 48:27:e2:20:47:a4 -> splitflap-20E22748 / sfgw_20E22748
    board B MAC 48:27:e2:20:5a:c8 -> splitflap-20E22748 / sfgw_20E22748
    esp_efuse_mac_get_default() writes the six MAC bytes in NETWORK order, and Arduino's
    EspClass reads that same buffer straight back as a LITTLE-endian uint64 -- so the LOW
    bytes of ESP.getEfuseMac() are the OUI (48:27:e2), which every Espressif chip shares.
    Casting it to uint32_t hands every board an identical id. The bytes that actually vary
    are mac[3..5].
    An MQTT broker evicts the client already holding a duplic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
    [common.h]
2026-07-14 v3.7.3 -- never watchdog-reboot the board mid web-OTA
    The stall check and the <20KB low-heap emergency reboot in loop() had no OTA guard. A web-OTA
    upload DELIBERATELY drives internal heap to the floor (a 1.45MB image streams in faster than
    flash absorbs it; min-free-heap has been observed at ~1KB near the end) and parks taskWeb inside
    handleClient() for the whole transfer. Either reboot would then reset the board MID-FLASH, onto
    the old image -- the "web OTA reaches ~98%, resets, comes back on the previous firmware" symptom.
    Both reboot paths now stand down while gOtaInProgress: if heap truly runs out, Update.write()
    fails and handleOTAUpload aborts cleanly; a watchdog reboot only guarantee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
    [common.h, main.cpp]
2026-07-14 v3.7.4 -- audit fixes: sfSetFlapConfigBySN overflow, OTA save guard, capabilities
    Findings from a multi-agent audit of the session's work, verified and fixed.
    HIGH -- sfSetFlapConfigBySN stack buffer overflow (remotely reachable). The frame is built
    with the cumulative-snprintf-return idiom into a 97-byte stack buffer, but the serial was never
    length-checked. snprintf() returns the length it WANTED to write, so a long sn drives n past the
    buffer; the next `snprintf(buf + n, sizeof(buf) - n, ...)` then writes through an out-of-bounds
    pointer with a size_t that has underflowed to ~SIZE_MAX. sn arrives unvalidated from POST
    /api/flap/flapconfig and the MQTT flapconfig topic. Now rejected up fr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
    [common.h, web.cpp]
2026-07-14 v3.8.0 -- POST /api/display/cells on the physical gateway (companion parity)
    The Matrix Portal gateway answers /api/display/cells; this wall only had the batch/char paths,
    so the companion drove the two walls through different endpoints. This adds the same endpoint
    here -- the "show this" half whose "what can you show" half is GET /api/capabilities -- so a
    client can drive either wall through one contract.
    Same JSON in ({start, step_ms, cells:[{ch|color|blank|skip}]}); hardware-appropriate frame out.
    The Matrix resolves each cell to a flap INDEX against its one uniform 237-flap reel (the only way
    to reach its lowercase/pictograph flaps). This wall's modules each carry their own 64-flap reel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
    [common.h, modules.h, openapi.yaml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]
2026-07-15 v3.9.0 -- branding parity, drop the Companion setting, panic-recovery safeguard
    UI, to match the companion app:
    * The header wordmark is just SPLIT-FLAP now; "GATEWAY" is text beside it (was one long
    split-flap SVG reading "SPLIT-FLAP GATEWAY"), and the firmware version moved out of the title
    bar into a quiet footer in the bottom-right of every tab.
    * The Companion App SETTINGS card is gone -- the companion registers its own URL, so there was
    nothing to set. The URL is now shown read-only on the Status page (matching the Matrix
    gateway, where this was already done).
    Fix: /logo.svg and /favicon.svg were served with a 7-day max-age and NO validator, so a changed
    logo kept serving the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
    [common.h, main.cpp, modules.h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]
2026-07-15 Self-heal a dead port-80 listener; log the running OTA slot at boot
    (Work from a parallel session, committed as found.) server.begin() ran
    once at boot with its result unchecked — a silent bind failure refused
    every request for the whole uptime. webEnsureListening() re-checks the
    ground truth (server.listening()) every 20 s from taskWeb and re-arms
    the listener only when it is genuinely down. Boot now logs which OTA
    slot is actually running and when it was built.
    [main.cpp, web.cpp]
2026-07-15 Capabilities: state how the wall moves — motion{kind: mechanical, settleMs: 4000}
    A client deciding what update rates are honest (a ticking seconds field is
    not, on hardware) had to infer motion from which endpoints exist — the
    cells wire-format flag standing in for 'drawn'. Brittle: this gateway HAS
    /api/display/cells since 3.8 and one day wants to advertise it. Motion is
    now a stated fact: mechanical, worst-case settle ~4 s (a full revolution).
    The Matrix Portal gateway answers the same key with kind drawn. Additive —
    a client that doesn't know the key sees the document it always saw.
    [web.cpp]
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2026-07-16 v3.11.0 — the hostname carries the board id: splitflap-gw-<6 hex>
    Two gateways on one LAN both called splitflap-gw fight over the mDNS
    name exactly the way they fought over the MQTT client id; boardId24()
    was built for that fix and the hostname now uses it too. Matches the
    Matrix Gateway's naming, so every gateway on a network answers at
    splitflap-gw-<id>.local, printed at boot.
    [common.h]
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2026-09-02 README: recovery when the web update fails, without developer tools
    Three no-toolchain routes -- retry after a reboot, a one-script espota
    push over Wi-Fi, and the Espressif browser flasher over USB -- with the
    detail that matters for the USB route: the app image at 0x10000 must be
    paired with boot_app0.bin at 0xE000, or a board that last updated over
    the air keeps booting the other slot. The release now ships boot_app0.bin
    alongside the app and factory images.
2026-09-03 BLOG: three projects, not two -- the companion as the third component
    Rewritten around three limitations: one firmware per module, a computer
    inside the display, and 'what do you actually show?'. The companion gets
    a full section (apps, compose, playlists, schedules, triggers, language,
    Home Assistant, the Vestaboard API, MCP, several walls, stateless
    storage in the gateway) and the splitflap-os plugin compatibility. The
    firmware and gateway sections are refreshed for what they do now
    (backup/restore by serial, flap sets, diagnostics; permanent registry,
    restore on boot, quiet time, capabilities). All screenshots replaced with
    the current ones from the wiki (August 2026), plus the ecosystem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
2026-09-14 v3.12.1 — display state broke past ~50 cells (unterminated batch flush)
    GET /api/display/state streams cells in 256-byte batches; every flush
    but the last sent the buffer without a terminator, so stale bytes leaked
    into the JSON and the Display and Calibration tabs failed to load on any
    grid larger than one batch (a 6x20 wall, for instance). Terminate before
    each flush.
    [common.h, web.cpp]
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2026-09-26 v3.13.1 — the quiet-time schedule overflowed the RTC task's stack
    quietScheduleTick ran on taskRTC (2 KB stack, ~1.4 KB used just reading
    the clock). Asserting Quiet Time from there sends bus frames through
    sfSetQuietTime -> sfHome -> rs485Send (336 B) -> mqttPublishMsg (976 B)
    plus printf: ~1.5 KB more, so a stack overflow, a panic and a reboot.
    With Restore on Boot enabled that was a loop: power-up homing, restore,
    quiet asserts, crash, boot again. The tick now runs on taskNetwork.
    restoreInit() also moves ahead of task creation so the lock is held
    before any task can touch the bus.
    [common.h, main.cpp]
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2026-10-17 v3.13.2 — the timezone setting was ignored; the clock always showed UTC
    configTime(0, 0, server) fetches UTC for the NTP sync, and the ESP32
    core's configTime() ends by writing TZ itself -- so it overwrote the
    configured zone with UTC0DST0 and every local-time conversion after the
    first sync returned UTC. Re-picking the zone appeared to work and then
    reverted, because changing it also forced a re-sync, which clobbered it
    again.
    The zone is re-applied after every sync through a single rtcApplyTZ()
    that holds timeMutex (setenv/tzset/localtime are not thread-safe in
    newlib, and the time is formatted from other tasks). Changing the zone no
    longer forces a re-sync: the clock is stored in UTC,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
2026-10-17 Monitor keeps every frame whole
    The ring stored 256 bytes per frame while a calibrated module's 'A'
    reply runs to 450-750, so the monitor showed a long reply cut short --
    in exactly the situation you would be using it to investigate. The ring
    entry is now TX_MAX_BYTES, in PSRAM (64 x ~812 B), and the response is
    streamed in TCP-sized chunks instead of built as one String: a full ring
    of whole frames escapes to ~150 KB. The debug/command text buffers and
    the MQTT frame payload keep their 256-byte cap on purpose -- they sit on
    6 KB task stacks and a 1 KB queue slot.
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2026-10-17 v3.15.0 — a soak test for the whole wall
    Every provisioned module, pass after pass, four reply sizes, for as many
    minutes as asked; a tally per module per size, a count of discarded and
    corrupt frames over the run, and a verdict that separates a bus losing
    long frames from a module failing at every size. Nothing moves. It holds
    the bus (BUSY, lease renewed per pass) and releases on finish or cancel.
    The probe, the motor self-tests and the soak refuse to run over each
    other. Verified on a 15-module wall: 229 queries in a minute, 0 misses.
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2026-10-17 Soak test: broadcast roll call, a write round trip, and a report that names the fault
    The soak now works the bus seven ways instead of four: a broadcast roll call (m*v) and a
    broadcast combined dump (m*A) score replies that go missing, arrive damaged, or arrive twice
    for one id; a write round trip nudges the home offset and one map entry, reads them back, puts
    them back and reads them back again. A value that cannot be confirmed restored is reported
    first, with the original, and the run never stops mid-restore.
    The result is a list of findings rather than a scoreboard: each names the modules, the evidence
    and what to do -- long frames lost but short ones fine reads as termination and cable,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
2026-10-17 A safety snapshot before the soak test, and one button to undo it
    The soak writes to modules, so it now reads every module's calibration into a snapshot file
    on the gateway before the first write, and can replay it through the same per-entry restore
    the boot restore uses: GET /api/flap/soak/snapshot to keep a copy, POST /api/flap/soak/rollback
    to put the whole wall back. The snapshot is a separate file from the user's stored backup and
    never overwrites it; the report offers the rollback where it names a value it could not put
    back, and says so when no snapshot could be taken.
    The module list in the sweep is static: 255 entries do not fit the soak task's 4 KB stack,
    which crashed the gateway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
2026-10-18 v3.15.1 - homing is maintenance, and a hold cannot outlive its job
    Issue #7: opening the Calibration tab holds the bus, and homing was gated as display content,
    so Home All and Home Motor answered 503 on the screen that needs homing most. Homing paints
    nothing; it is now refused only while the bus is reserved (a restore) or while a machine-run
    test is measuring it. The dashboard's request tag is no longer the only way to recognise the
    operator either: the address that took a hold is remembered, so a proxy that drops unknown
    headers, an older page or a second operator tool cannot be locked out of its own hold.
    Reported separately: a cancelled soak could leave the wall paused until its lease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
2026-10-19 v3.16.0 - spend the PSRAM where it buys evidence
    The board has 8 MB of PSRAM and was using 2.8% of it, while the bus history was sized for a
    board with none. The monitor ring goes from 64 frames to 512 (550 KB of PSRAM): a minute of a
    busy wall instead of a few seconds. Readers are handed at most 64 frames per request and
    resume where they left off, by sequence number rather than slot index, so a long history
    cannot become a half-megabyte response and a reader that was away is told how many frames it
    missed instead of silently seeing a hole.
    New: an incident log (1024 entries, PSRAM) recording what went wrong and whose it was --
    discarded frames, replies that would not parse, reads that onl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
2026-10-19 v3.17.0 - record the soak's raw traffic and let it be downloaded
    A report says what happened; a trace says what was on the wire. For a wall you cannot touch --
    someone else's, or your own reproduced locally -- that is the whole investigation. The last
    run's trace is kept whether or not it was clean, because a trace from a healthy wall is the
    baseline a broken one is read against.
    Two constraints shaped it. Nothing touches flash while the test runs: flash writes stall the
    cache and the test measures milliseconds, so the capture accumulates in PSRAM and is written
    once, after the bus is released. And memory is bounded with the newest data winning: a
    64-module half-hour run is ~144,000 frames,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
2026-10-19 Soak trace: record frames whole, 4 MB ring
    Cutting long replies to 96 bytes saved 29% against a real run and cost the bytes a trace
    exists for. Frames are now recorded whole and the ring is 4 MB: measured at ~2 KB per
    module-minute, a 64-module half-hour run is 3.6 MB and fits. Coverage checked against the
    gateway's own counters: 453 of 453 frames.
    The format buffer moved to PSRAM with the payload limit (a whole escaped frame is 4 KB and
    internal RAM is the scarce memory), which left a sizeof() measuring a pointer instead of the
    buffer -- every frame line was malformed and dropped until it was fixed. traceFrames() now
    reports the count so 'is it recording' is answerable without downloading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
2026-10-19 v3.17.1 - address modules by id, not by serial, when the id is known
    A calibration read went out as mXD<20-hex-serial>, 24 bytes, where m12d does the same job in 6
    -- and every module on the bus receives every command, so the whole wall paid the difference on
    every read. Measured on the soak trace: command bytes fell from 5,742 to 2,058 over two
    minutes, 64% less, with the same 240 queries answered and no retries needed.
    The serial form moves to the second ask, where it earns its length: if the short command goes
    unanswered, a stale or duplicated id is exactly the plausible explanation, and a serial-
    addressed read cannot be answered by the wrong module. sfReadDump() takes an alternate fram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
2026-10-19 v3.18.0 - checksummed frames, and the counters a v33 module keeps
    Module firmware v33 added an optional ~HHHH<frame> format (CRC-16/CCITT-FALSE) and four
    counters of its own. This is the gateway side of both, decided per module from the version
    that module reported, so a mixed wall works and v32 modules see exactly the traffic they saw
    before.
    Checksums go on the exchanges where a corrupted frame does damage or costs a retry -- reads,
    writes, restores, the version query -- and not on display content, where five extra bytes on a
    six-byte command is 80% more traffic for a frame the next update overwrites. Every reply that
    arrives checksummed is verified; one that fails is dropped rather than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
2026-10-20 v4.0.0: measurements at eighteen modules, and the cancel behaviour
    18 modules v35/v36 -> v36 in one pass, 83 s, 18 of 18, with the one v32 module on the same bus
    skipped and undisturbed by 240 broadcast page frames. Cancel mid-send stopped 3.2 s after the
    request with the bus released; a second run recovered all 18 in 82 s; a named subset of three
    updated while the other fifteen stayed where they were. Zero discards, rejects, checksum
    failures or incidents throughout.
    Also fixed what the scale exposed: the status reply was built in a fixed buffer and truncated
    mid-row at 18 modules, so it now streams like the other list endpoints.
2026-10-20 Module firmware card: plainer wording
    The card explained the bootloader, the image size and what happens on power loss. None of that
    helps someone deciding whether to press the button; it belongs in the documentation, which has
    it. What is left says what it does, how long it takes, what to upload and which modules are
    skipped.
2026-10-20 Fix the maintenance banner outstaying the work
    The dashboard funnels its pollers through one gate so the single-threaded web server is never
    hammered: one request per 150 ms. The gate DROPPED a call that landed inside the window rather
    than deferring it, and the same poller always lost -- the status poll runs every three seconds
    and draws the banner, the bus monitor polls every six hundred milliseconds, so collisions were
    frequent and each one cost the banner another three seconds. Measured before the fix: fifteen
    seconds to appear, and on the Calibration tab it did not appear at all within four. Reloading
    looked like the cure because the page polls once on load.
    A gated call is now deferre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
2026-10-20 Respin 4.0.0 with the banner fix
    The maintenance banner outstayed the work it belonged to, sometimes until the page was
    reloaded. The dashboard's poll gate dropped a call that landed inside its 150 ms window
    instead of deferring it, and the status poll -- three seconds apart, and the one that draws the
    banner -- lost those races to the monitor poll six hundred milliseconds apart. Gated calls are
    deferred now, one pending per poller, and the page refreshes as soon as it takes or releases a
    hold itself.
    Folded into the 4.0.0 notes rather than shipped as its own release.
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2026-10-21 4.1.0 notes: a broadcast carries a byte, not a symbol
    The release notes and ARCHITECTURE both wrote the broadcast case as
    `m*-♥`, which is not a frame: the wire has no byte for a heart, which is
    the whole reason the letters exist. What a broadcast would actually send
    is `m*-h` -- the heart on the reels printed with one, and a byte every
    other module's reel does not contain, so it homes. That is what the
    per-module expansion avoids, and now what both documents say.
    Also: the extractor fix recovered 147 previously untranslatable strings,
    not 157. The 157 came from a diff that also counted this release's own
    new strings; 147 is what rule (c) finds on the pre-change dashboard.
    And /api/flap/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
2026-10-25 Updater: find the gateway again by address when the name will not resolve
    The page polls for the board coming back on whatever origin it was
    opened from. Opened by mDNS name -- which is what the docs tell people
    to use -- that poll is only as reliable as .local resolution at the
    exact moment the board returns: a cached record, an AP that blocks
    multicast between bands, or an Android phone (which mostly does not do
    .local at all) turns a flash that worked into "the gateway has not come
    back after 90 s", and the person reports a broken updater.
    The page now carries the station's own IP and tries the origin first,
    then the address; the dashboard link afterwards points at whichever
    answered. Ve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
2026-10-25 v4.2.0: the gateway has a name, and it is splitflap
    It answers at http://splitflap.local, and Settings > Network Name
    changes it: lowercase letters, digits and hyphens, applied at once with
    no reboot. GET /api/config reports it as mdnsName; POST
    /api/config/settings {"mdnsName":"..."} sets it and replies with the
    effective name and URL; blank puts it back to the default.
    Every board used to derive a unique name from its chip id
    (splitflap-gw-a1b2c3.local), which never collided and which nobody could
    remember. One wall is the normal case, so the normal case gets the short
    name, and anyone running two renames the second -- the UI says so, since
    mDNS cannot tell two of them apart.
    On upgrade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

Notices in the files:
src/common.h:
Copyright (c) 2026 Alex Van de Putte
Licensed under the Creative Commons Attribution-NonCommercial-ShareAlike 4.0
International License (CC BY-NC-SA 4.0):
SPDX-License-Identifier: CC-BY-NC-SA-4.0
